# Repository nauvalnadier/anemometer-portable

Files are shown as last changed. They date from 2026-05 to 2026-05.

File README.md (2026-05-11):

# Anemometer Portable

A portable anemometer built with an Optocoupler sensor for wind speed measurement and HMC5883L magnetometer for wind direction, controlled by an Arduino UNO R3 microcontroller with automatic MicroSD data logging.

> Undergraduate thesis project — Atmospheric and Planetary Science, ITERA 2026

---

## Description

This project presents the hardware design, firmware, and documentation for a low-cost portable anemometer. The device uses an Optocoupler sensor to count rotor pulses from a 3-cup anemometer and an HMC5883L magnetometer to detect wind direction via a rotating wind vane with an embedded magnet. All measurements are timestamped using a DS3231 RTC module and logged to a MicroSD card every 5 seconds.

The instrument was calibrated against a Davis AWS standard anemometer, achieving a post-calibration uncertainty of ±0.3046 m/s and a wind direction accuracy of CSI = 1.00 across 8 cardinal directions using the Lavdas method.

---

## Specifications

### System Overview

| Parameter | Value |
|---|---|
| Type | 3-cup portable anemometer with wind vane |
| Microcontroller | Arduino UNO R3 (ATMega328P, 16 MHz) |
| Power Supply | 2× Li-ion 18650 battery |
| Data Storage | MicroSD card (TXT format, FAT32) |
| Communication | I2C (sensors + RTC), SPI (MicroSD) |

### Wind Speed — Optocoupler Sensor

| Parameter | Value |
|---|---|
| Sensor | Optocoupler LM393 |
| Encoder | Disk encoder, 16 slots, D = 60 mm |
| Cup type | Hemisphere, D = 40 mm |
| Arm length | 60 mm |
| Bearing | 608zz |
| Calibrated speed range | 1.2–5.5 m/s |
| Minimum threshold | 0.43 m/s |
| Uncertainty (95%) | ±0.3046 m/s |
| Calibration equation | y = 10.51x + 0.43 |
| Pearson r (post-calibration) | 0.9556 |
| RMSE (post-calibration) | 0.1523 m/s |
| Reference standard | Davis AWS anemometer |
| Operating voltage | 3.3–5V |

### Wind Direction — HMC5883L Magnetometer

| Parameter | Value |
|---|---|
| Sensor | HMC5883L 3-axis magnetometer |
| Measurement range | ±1 to ±8 gauss |
| Angular resolution | 1–2° |
| Operating voltage | 2.7–6.5V |
| Interface | I2C |
| Directions supported | 8 (N, NE, E, SE, S, SW, W, NW) |
| CSI (Lavdas method) | 1.00 |
| POD | 1.00 |
| FAR | 0.00 |

### Data Logging

| Parameter | Value |
|---|---|
| Sampling rate | 1 second |
| Output interval | Every 5 seconds (average of 5 samples) |
| SD write interval | Every 1 minute (12 data points per write) |
| RTC module | DS3231 |
| Output format | `DD/MM/YYYY HH:MM:SS  speed(m/s)  direction(°)` |

### Physical Dimensions

| Part | Dimension |
|---|---|
| Housing 1 (main box) | 96 × 84 × 105 mm |
| Housing 2 (top box) | 96 × 84 × 48 mm |
| Support pipe | H = 123 mm |
| Wind vane blade | 102 × 75 mm |
| Wind vane arm | L = 150 mm |
| Magnet holder | D = 5 mm |
| Estimated total print time | ~12–30 hours (depends on printer settings) |

---

## Bill of Materials

| No. | Component | Qty | Notes |
|---|---|---|---|
| 1 | Arduino UNO R3 | 1 | ATMega328P, 16 MHz |
| 2 | Optocoupler LM393 | 1 | Digital output, 3.3–5V |
| 3 | HMC5883L Magnetometer | 1 | I2C, 2.7–6.5V, 1–2° accuracy |
| 4 | RTC DS3231 | 1 | I2C timekeeping module |
| 5 | MicroSD Adapter + SD Card | 1 | SPI interface, FAT32 |
| 6 | 18650 Battery + Holder | 2 | Rechargeable Li-ion |
| 7 | Jumper Wires | — | Male-to-male & male-to-female |
| 8 | Bearing 608zz | 2 | Cup axis + wind vane axis |
| 9 | Neodymium Magnet | 1 | For wind vane, D ±5 mm |
| 10 | 3D Printed Parts | — | See `hardware/stl/` |

---

## Wiring

```
Arduino UNO R3
├── Digital Pin 2  →  Optocoupler (OUT)
├── SDA (A4)       →  HMC5883L (SDA) + DS3231 (SDA)
├── SCL (A5)       →  HMC5883L (SCL) + DS3231 (SCL)
├── Pin 10         →  MicroSD (CS)
├── Pin 11         →  MicroSD (MOSI)
├── Pin 12         →  MicroSD (MISO)
├── Pin 13         →  MicroSD (SCK)
├── 5V             →  VCC all sensors
└── GND            →  GND all sensors
```

See full wiring diagram in [`hardware/schematic/`](hardware/schematic/)

---

## 3D Printing

STL files are available in [`hardware/stl/`](hardware/stl/)

> **Note:** Print time estimates below are approximate and may vary
> significantly depending on printer model, speed settings, and slicer
> configuration. Total estimated time ranges from 12–30 hours.

| File | Part | Est. Print Time |
|---|---|---|
| `housing_1.stl` | Main box (96×84×105 mm) | ~4 hrs |
| `housing_2.stl` | Top box (96×84×48 mm) | ~2 hrs |
| `backdoor.stl` | Back door | ~30 min |
| `top_cover.stl` | Top cover | ~30 min |
| `support_pipe.stl` | Support pipe (H=123 mm) | ~1 hr |
| `disk_encoder.stl` | 16-slot encoder disk (D=60 mm) | ~45 min |
| `cup_anemometer.stl` | 3× hemisphere cup (D=40 mm) | ~1.5 hrs |
| `wind_vane.stl` | Wind vane (arm 150 mm, blade 102×75 mm) | ~1 hr |
| `magnet_holder.stl` | Magnet holder (D=5 mm) | ~15 min |

Recommended print settings:
- Material: PLA or PETG
- Layer height: 0.2 mm
- Infill: 20–30%
- Support: required for `cup_anemometer.stl` and `wind_vane.stl`

---

## Assembly

### Mechanical

1. Install both bearing 608zz — one into the cup anemometer dock 
   and one into the magnet holder
2. Before attaching the support pipe, connect the disk encoder 
   to the bottom of the cup anemometer
3. Install the neodymium magnet into the inner wall of the 
   magnet holder
4. Insert the support pipe through the cup anemometer bearing, 
   the magnet holder bearing, and dock it into housing 2
5. Assemble the remaining parts following the 3D design — 
   the final result should match the device photo in `docs/images/`

### Electronics

1. Place the Optocoupler sensor inside housing 2, positioned 
   directly at the disk encoder rotation path
2. Route the HMC5883L cable through the support pipe before 
   final assembly — the sensor sits statically at the center 
   of the magnet holder while the magnet holder itself rotates 
   with the wind vane above it
3. Connect all remaining components according to the wiring 
   diagram
4. Place the assembled electronics inside housing 1
5. Ensure cables do not obstruct the disk encoder or the 
   Optocoupler gap

### Firmware Upload

1. Install Arduino IDE
2. Install all required libraries (see Dependencies)
3. Open `firmware/anemometer_main/anemometer_main.ino`
4. Select board: **Arduino UNO** and the correct port
5. Click **Upload**

---

## Dependencies

Install via Arduino IDE Library Manager:

| Library | Author |
|---|---|
| DS3232RTC | Jack Christensen |
| Streaming | Mikal Hart |
| Adafruit HMC5883 Unified | Adafruit |
| Adafruit Unified Sensor | Adafruit |

Built-in (no installation required): `SD`, `SPI`, `Wire`

---

## Getting Started

### First Time Setup

**1. Set RTC time**

Open Serial Monitor at baud rate **9600** and send a string in the following format:
```
YYMMDDHHmmss
```
Example — May 11, 2026, 08:30:00:
```
260511083000
```

**2. Prepare SD Card**

- Format the SD card to **FAT32**
- Insert into the MicroSD adapter slot
- `datalog.txt` is created automatically on first boot

**3. Power on**

- Ensure 18650 batteries are fully charged
- Power on the device — data logging starts automatically

### Reading Data

Data is stored in `datalog.txt` in the following format:
```
DD/MM/YYYY HH:MM:SS  velocity(m/s)  direction(°)
```

Example output:
```
11/05/2026 08:30:00  1.23456  270.3
11/05/2026 08:30:05  1.45678  268.7
11/05/2026 08:30:10  0.00000  271.0
```

A velocity of `0.00000` indicates wind speed below the minimum threshold (< 0.43 m/s).

---

## Working Principle

**Wind Speed:**
```
v_raw       = (π × d × pulses / n_slots) / Δt
v_corrected = (10.51 × v_raw) + 0.43
```

**Wind Direction:**
```
θ       = atan2(Y, X) → converted to azimuth 0–360°
azimuth = (360 - θ) % 360   ← corrected for CCW magnet rotation
```

---

## Repository Structure

```
anemometer-portable/
├── README.md
├── firmware/
│   └── anemometer_main/
│       └── anemometer_main.ino
├── hardware/
│   ├── stl/               <- 3D print files (.stl)
│   └── schematic/         <- Wiring diagram
└── docs/
    └── images/            <- Device photos
```

---

## Authors

**Nauval Nadier Nashrullah**
Atmospheric and Planetary Science, ITERA — 2026
NIM: 122290047

Advisors: Alfiah Rizky Diana Putri, S.T., M.Eng. & Alvin Pratama, S.Si., M.T.

---

## License

This project is licensed under the MIT License.

---

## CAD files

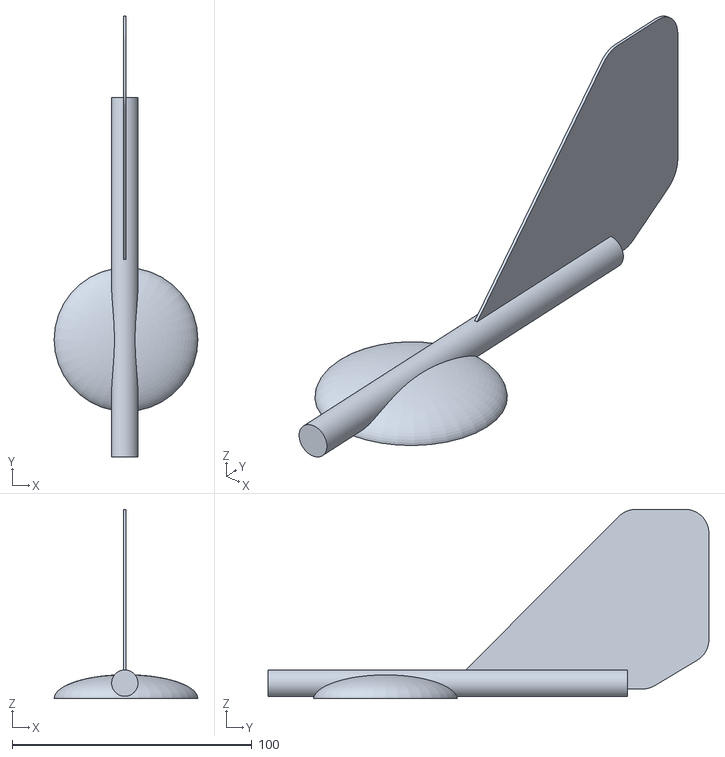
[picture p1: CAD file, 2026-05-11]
hardware/stl/wind_vane.stl
60.0 x 184.0 x 79.0

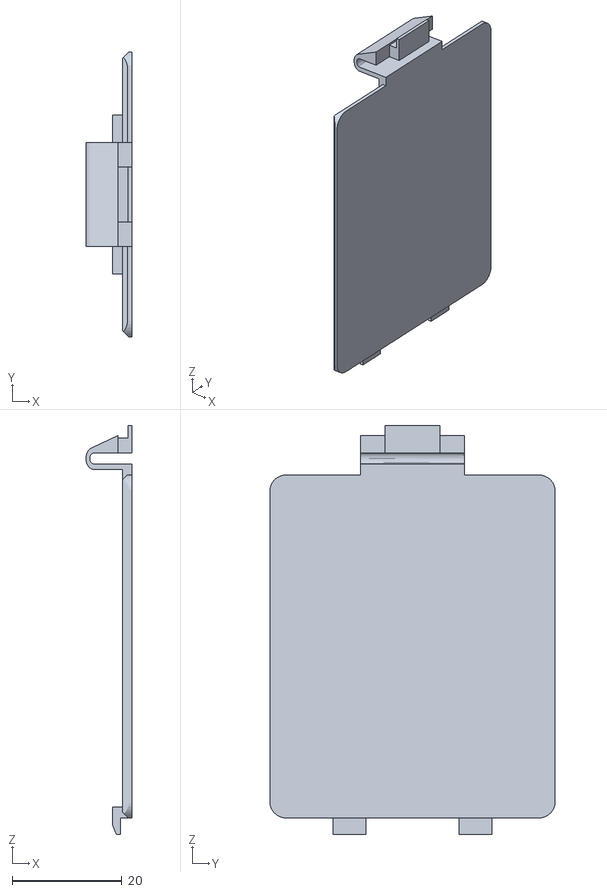
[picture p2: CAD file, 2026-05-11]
hardware/stl/backdoor.stl
8.40 x 52.0 x 74.5

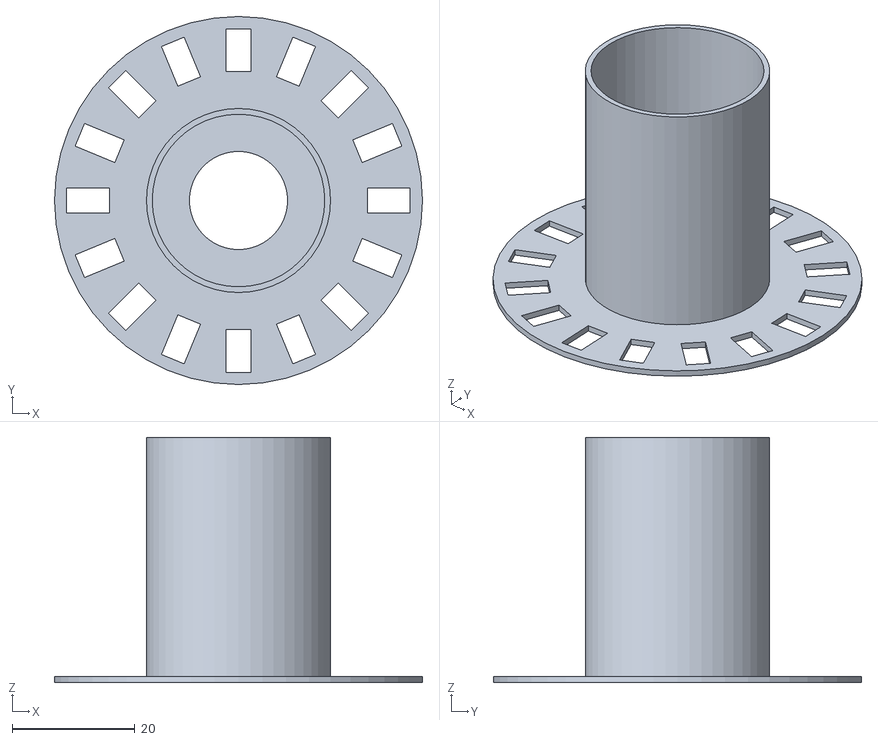
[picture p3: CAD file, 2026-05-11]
hardware/stl/disk_encoder.stl
60.0 x 60.0 x 40.0

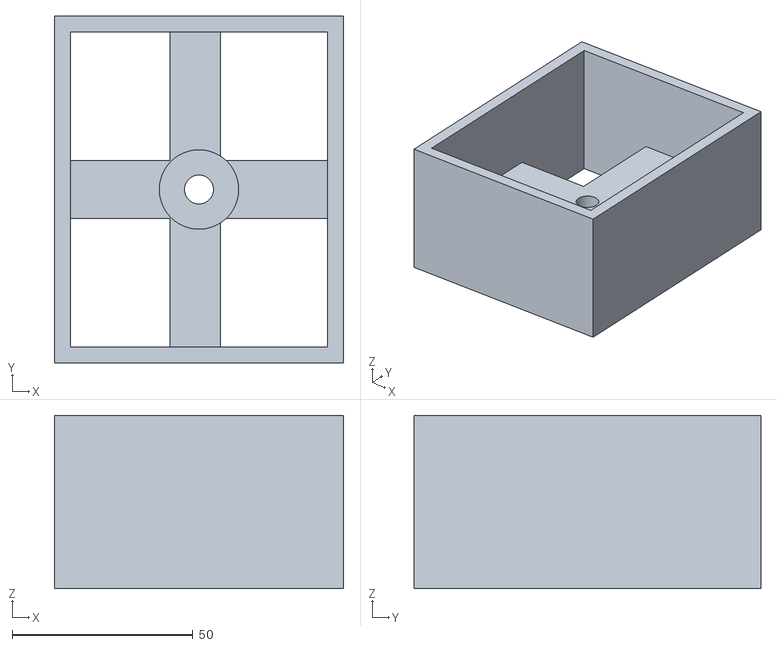
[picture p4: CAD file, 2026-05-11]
hardware/stl/housing_2.stl
80.0 x 96.0 x 48.0

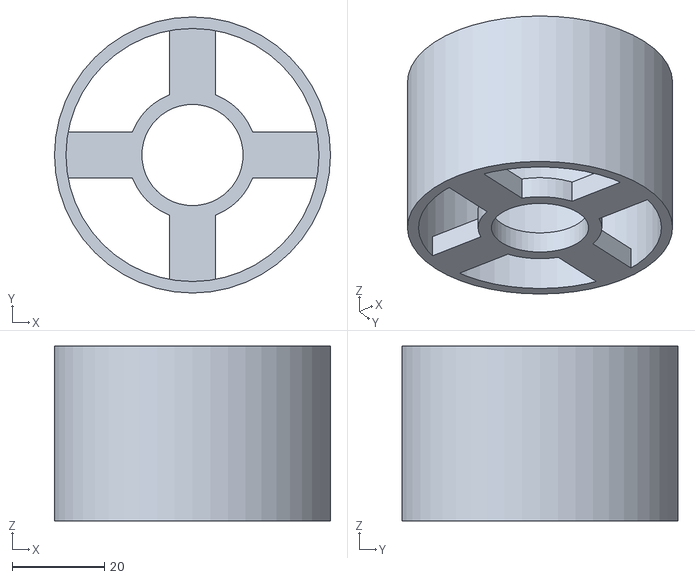
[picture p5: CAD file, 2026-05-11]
hardware/stl/magnet_holder.stl
60.0 x 60.0 x 38.0

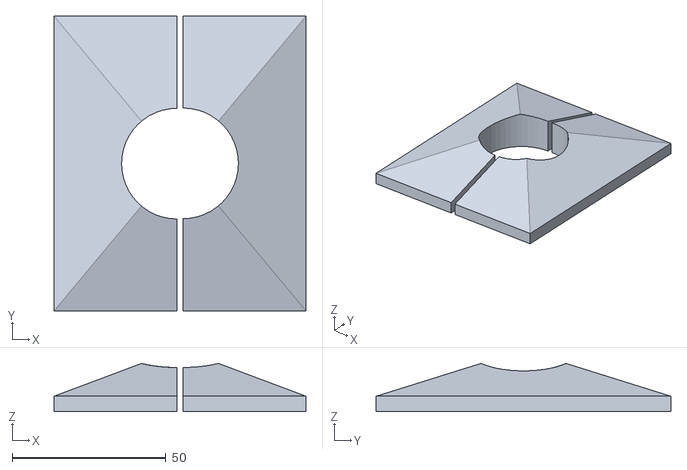
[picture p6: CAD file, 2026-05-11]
hardware/stl/top_cover.stl
82.0 x 95.9 x 15.7

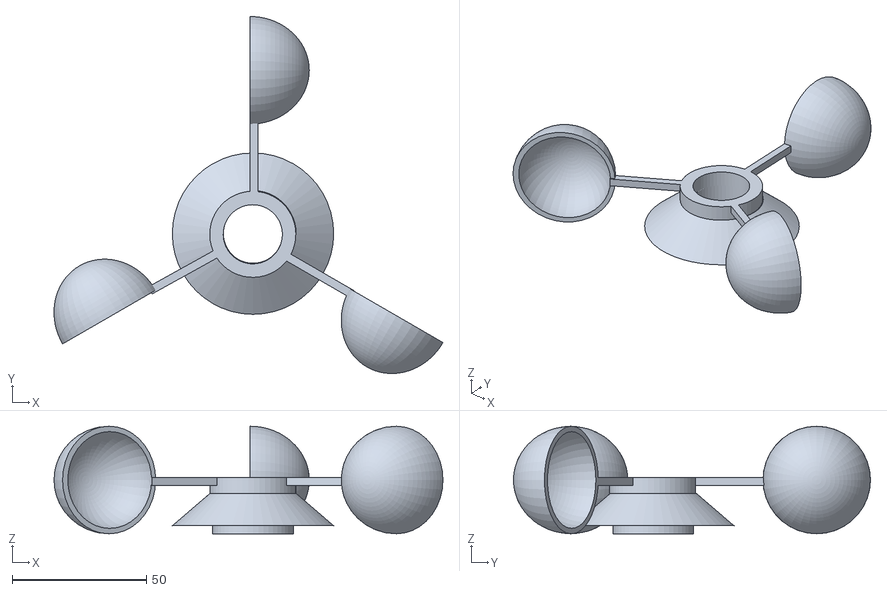
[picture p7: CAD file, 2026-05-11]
hardware/stl/cup_anemometer.stl
144.6 x 132.8 x 40.0

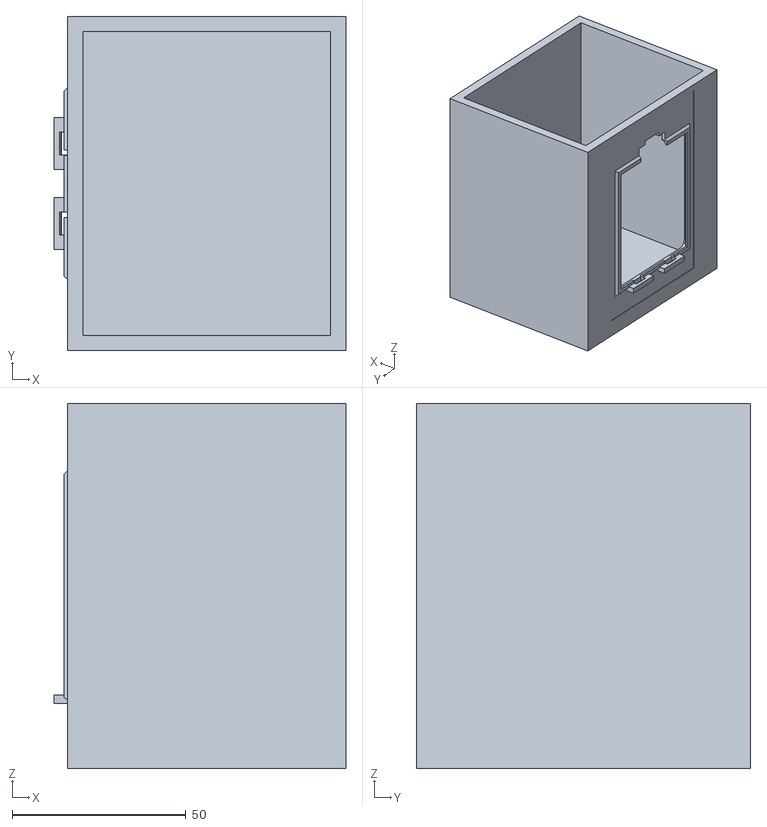
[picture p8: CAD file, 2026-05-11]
hardware/stl/housing_1.stl
83.9 x 96.0 x 105.0

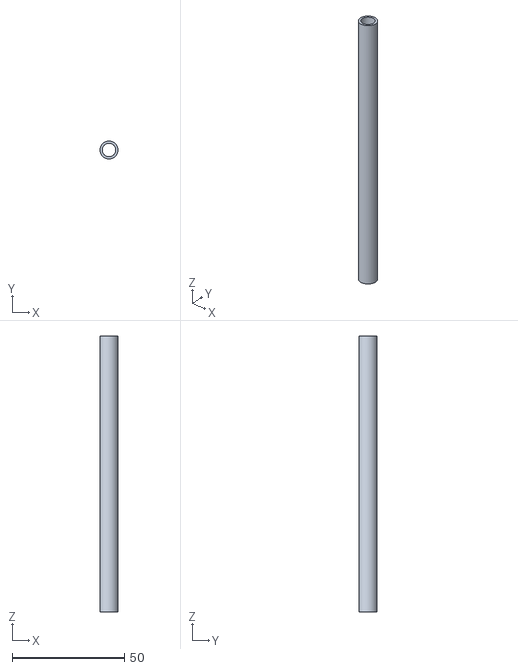
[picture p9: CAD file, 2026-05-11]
hardware/stl/support_pipe.stl
8.00 x 8.00 x 123.0

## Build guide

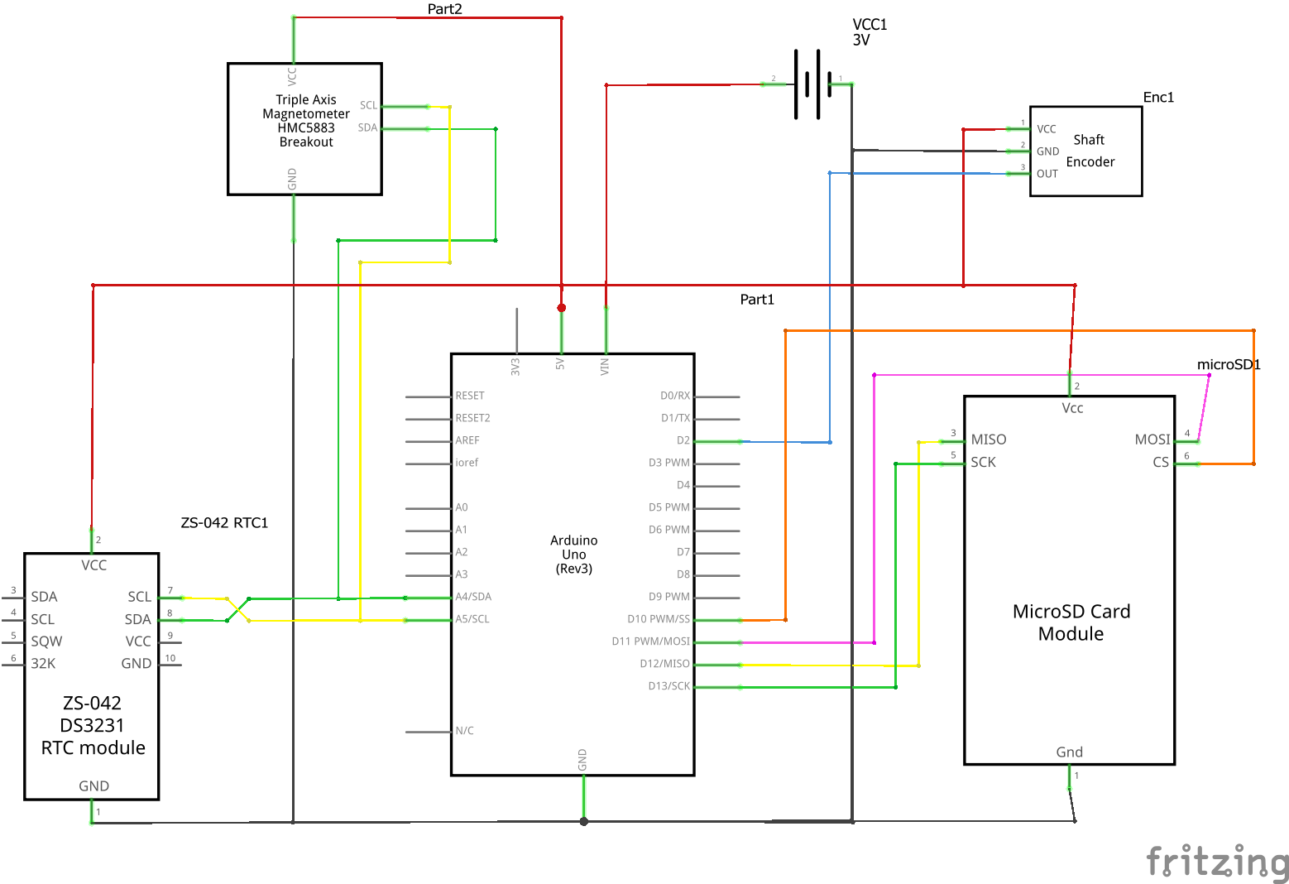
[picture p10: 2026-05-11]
hardware/schematic/wiring_diagram.png

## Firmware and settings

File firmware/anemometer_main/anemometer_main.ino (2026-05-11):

#include <DS3232RTC.h>
#include <Streaming.h>
#include <Wire.h>
#include <Adafruit_Sensor.h>
#include <Adafruit_HMC5883_U.h>
#include <SPI.h>
#include <SD.h>

DS3232RTC myRTC;
Adafruit_HMC5883_Unified mag = Adafruit_HMC5883_Unified(12345);

int OptoPin = 2;
float velocity = 0;
volatile byte pulses = 0;
unsigned long timeOld = 0;
const float pulsesperturn = 16.0;
const float wheel_diameter = 0.06;
static volatile unsigned long debounce = 0;

const int SAMPLE_INTERVAL = 5000;
const int NUM_SAMPLES = 5;

const float CALIBRATION_SLOPE = 10.51;
const float CALIBRATION_INTERCEPT = 0.43;

const int BUFFER_SIZE = 12;
struct DataPoint {
  time_t timestamp;
  float velocity;
  float azimuth;
};
DataPoint dataBuffer[BUFFER_SIZE];
int bufferIndex = 0;

float velocitySamples[NUM_SAMPLES];
float azimuthSamples[NUM_SAMPLES];
int sampleIndex = 0;
unsigned long lastSampleTime = 0;
unsigned long intervalStart = 0;

const int chipSelect = 10;
bool sdCardAvailable = false;

void setup() {
  Wire.begin();
  Serial.begin(9600);

  myRTC.begin();
  setSyncProvider([]() { return myRTC.get(); });
  Serial.println(F("ANEMOMETER PORTABEL by Nauval Nadier N"));
  Serial.print(F("RTC Sync: "));
  Serial.println(timeStatus() != timeSet ? F("FAIL!") : F("OK"));

  Serial.print(F("Initializing SD card..."));
  if (!SD.begin(chipSelect)) {
    Serial.println(F("FAIL!"));
    sdCardAvailable = false;
  } else {
    Serial.println(F("OK"));
    sdCardAvailable = true;
    if (!SD.exists("datalog.txt")) {
      File dataFile = SD.open("datalog.txt", FILE_WRITE);
      if (dataFile) {
        dataFile.println(F("========================================"));
        dataFile.println(F("ANEMOMETER PORTABEL by Nauval Nadier N"));
        dataFile.println(F("========================================"));
        dataFile.println(F("Date       Time      Velocity(m/s)  Azimuth(°)"));
        dataFile.println(F("========================================"));
        dataFile.close();
        Serial.println(F("File header created"));
      }
    }
  }

  if (!mag.begin()) {
    Serial.println(F("Compass not detected! Check wiring."));
    while (1);
  }
  mag.setMagGain(HMC5883_MAGGAIN_8_1);
  Serial.println(F("Compass initialized"));

  pinMode(OptoPin, INPUT);
  attachInterrupt(digitalPinToInterrupt(OptoPin), counter, RISING);
  Serial.println(F("Wind speed sensor initialized"));

  Serial.println();
  Serial.println(F("========================================"));
  Serial.println(F("Date       Time      Velocity(m/s)  Azimuth(°)"));
  Serial.println(F("========================================"));

  intervalStart = millis();
  lastSampleTime = millis();
  bufferIndex = 0;
}

void loop() {
  unsigned long timeNew = millis();

  if (timeNew - timeOld >= 1000) {
    noInterrupts();
    unsigned int currentPulses = pulses;
    pulses = 0;
    interrupts();

    float rawVelocity = (PI * wheel_diameter * (currentPulses / pulsesperturn))
                        / ((timeNew - timeOld) / 1000.0);
    velocity = (CALIBRATION_SLOPE * rawVelocity) + CALIBRATION_INTERCEPT;
    if (velocity < 0) velocity = 0;

    sensors_event_t event;
    mag.getEvent(&event);
    float a = atan2(event.magnetic.y, event.magnetic.x) * 180.0 / PI;
    if (a < 0) a += 360.0;

    velocitySamples[sampleIndex] = velocity;
    azimuthSamples[sampleIndex]  = a;
    sampleIndex++;

    timeOld = timeNew;
  }

  if (timeNew - intervalStart >= SAMPLE_INTERVAL && sampleIndex >= NUM_SAMPLES) {
    float avgVelocity = 0;
    for (int i = 0; i < NUM_SAMPLES; i++) avgVelocity += velocitySamples[i];
    avgVelocity /= NUM_SAMPLES;

    float sumSin = 0, sumCos = 0;
    for (int i = 0; i < NUM_SAMPLES; i++) {
      float rad = azimuthSamples[i] * PI / 180.0;
      sumSin += sin(rad);
      sumCos += cos(rad);
    }
    float avgAzimuth = atan2(sumSin / NUM_SAMPLES, sumCos / NUM_SAMPLES) * 180.0 / PI;
    if (avgAzimuth < 0) avgAzimuth += 360.0;

    // Koreksi arah berlawanan jarum jam
    avgAzimuth = fmod((360.0 - avgAzimuth), 360.0);

    time_t t = now();

    printDateTime(t);
    Serial.print(F("  "));
    Serial.print(avgVelocity, 5);
    Serial.print(F("      "));
    Serial.print(avgAzimuth, 1);
    Serial.println();

    dataBuffer[bufferIndex].timestamp = t;
    dataBuffer[bufferIndex].velocity  = avgVelocity;
    dataBuffer[bufferIndex].azimuth   = avgAzimuth;
    bufferIndex++;

    Serial.print(F("Buffer: "));
    Serial.print(bufferIndex);
    Serial.print(F("/"));
    Serial.println(BUFFER_SIZE);

    if (bufferIndex >= BUFFER_SIZE) {
      flushBufferToSD();
      bufferIndex = 0;
    }

    sampleIndex   = 0;
    intervalStart = timeNew;
  }

  if (Serial.available() >= 12) setRTCTime();
}

void flushBufferToSD() {
  if (!sdCardAvailable) {
    Serial.println(F("SD card not available, data lost!"));
    return;
  }
  File dataFile = SD.open("datalog.txt", FILE_WRITE);
  if (dataFile) {
    for (int i = 0; i < bufferIndex; i++) {
      time_t t = dataBuffer[i].timestamp;
      if (day(t)    < 10) dataFile.print('0'); dataFile.print(day(t));    dataFile.print('/');
      if (month(t)  < 10) dataFile.print('0'); dataFile.print(month(t));  dataFile.print('/');
      dataFile.print(year(t));                 dataFile.print(' ');
      if (hour(t)   < 10) dataFile.print('0'); dataFile.print(hour(t));   dataFile.print(':');
      if (minute(t) < 10) dataFile.print('0'); dataFile.print(minute(t)); dataFile.print(':');
      if (second(t) < 10) dataFile.print('0'); dataFile.print(second(t)); dataFile.print("  ");
      dataFile.print(dataBuffer[i].velocity, 5);
      dataFile.print("      ");
      dataFile.print(dataBuffer[i].azimuth, 1);
      dataFile.println();
    }
    dataFile.close();
    Serial.print(F("Flushed "));
    Serial.print(bufferIndex);
    Serial.println(F(" records to SD card"));
  } else {
    Serial.println(F("Error opening datalog.txt"));
  }
}

void counter() {
  if (digitalRead(OptoPin) && (micros() - debounce > 500) && digitalRead(OptoPin)) {
    debounce = micros();
    pulses++;
  }
}

void printDateTime(time_t t) { printDate(t); Serial.print(F(" ")); printTime(t); }
void printTime(time_t t)     { printI00(hour(t), ':'); printI00(minute(t), ':'); printI00(second(t), ' '); }
void printDate(time_t t)     { printI00(day(t), '/'); printI00(month(t), '/'); Serial.print(year(t)); }
void printI00(int val, char delim) {
  if (val < 10) Serial.print('0');
  Serial.print(val);
  if (delim > 0) Serial.print(delim);
}

void setRTCTime() {
  if (bufferIndex > 0) { flushBufferToSD(); bufferIndex = 0; }
  int y = Serial.parseInt();
  if (y >= 100 && y < 1000) {
    Serial.println(F("Error: Year must be two digits or four digits!"));
  } else {
    tmElements_t tm;
    tm.Year   = (y >= 1000) ? CalendarYrToTm(y) : y2kYearToTm(y);
    tm.Month  = Serial.parseInt();
    tm.Day    = Serial.parseInt();
    tm.Hour   = Serial.parseInt();
    tm.Minute = Serial.parseInt();
    tm.Second = Serial.parseInt();
    time_t t = makeTime(tm);
    myRTC.set(t); setTime(t);
    Serial.print(F("RTC set to: ")); printDateTime(t); Serial.println();
    while (Serial.available() > 0) Serial.read();
  }
}

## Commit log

2026-05-11 Add Arduino firmware for anemometer main program
2026-05-11 placeholder for stl
2026-05-11 placeholder for schematic
2026-05-11 Update estimated total print time to ~30 hours
2026-05-11 Revise estimated total print time in README
    Updated estimated total print time to reflect variability based on printer settings.
2026-05-11 Update README with improved assembly instructions
    Revised assembly instructions for clarity and detail.
2026-05-11 Rename STL files for consistency
